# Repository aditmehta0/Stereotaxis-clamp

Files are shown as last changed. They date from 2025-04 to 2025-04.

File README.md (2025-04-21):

# 🧠 Stereotaxic Clamp Project

## 📌 Project Intent

This repository documents the design and fabrication of a **stereotaxic clamp system** used in **rodent neurosurgery**. The clamp securely positions a secondary 6 mm rod exactly **1 inch (25.4 mm)** from a primary vertical rod, enabling precise alignment of implants, microinjectors, or electrodes over a mouse skull. Two clamp designs are provided, each available for **CNC machining** and **3D printing**.

The goal is to provide an **accessible, modifiable, and affordable open-source solution** for labs conducting small animal stereotaxic procedures.

---

## 📁 Repository Structure

```
Stereotaxic_Clamp/
├── Design_Files/
│   ├── DesignB/
│   │   ├── CNC/
│   │   │   ├── DesignB_CNC_BOM.xlsx
│   │   │   └── CAD_Files/
│   │   └── 3D_Print/
│   │       ├── DesignB_3DPrinted_BOM.xlsx
│   │       └── STL_Files/
│   │       └── Instructions/
│   │           └── Assembly_Guide.md
│   └── DesignA/
│       ├── 3D_Print/
└── README.md                   # This project overview file
```

---

## 🧩 Designs Overview

- **DesignA**: Block-style clamp with parallel rod positioning and dual set screws for system where rod end insertion is not an option.
- **DesignB**: Simplified geometry clamp, optimized for rod end point insertion, less parts, simplified printing.

Each design includes:
- Fully dimensioned CAD files (`.STEP`, `.SLDPRT`)
- Ready-to-print STL files (for 3D printing)
- Manufacturing instructions for CNC or SLA
- Detailed BOMs with sourcing links

---
## 📊 Cost Comparison – DesignA

| Production Method | Total Cost (100 Units) | Cost per Part |
|---|---|---|
| 3D Printing (In-House) | $159.00 | $1.59 |

## 📊 Cost Comparison – DesignB

| Production Method | Total Cost (100 Units) | Cost per Part |
|---|---|---|
| 3D Printing (In-House) | $133.00 | $1.33 |
| CNC In-House | $494.44 | $4.94 |
| CNC External Vendor | $1,124.44 | $11.24 |

---

## 🧑‍🔬 Target Users

- Neuroscience and bioengineering labs using rodent stereotaxic frames
- Researchers needing affordable accessories for small animal surgeries
- Makers and engineers customizing implant tools for preclinical models

---

## 📬 Contributions

Feel free to fork this repo and submit pull requests with design improvements or additional variants. Design2 is ongoing — feedback welcome!

---

## 📜 License

This repository is shared under the MIT License. Attribution appreciated.

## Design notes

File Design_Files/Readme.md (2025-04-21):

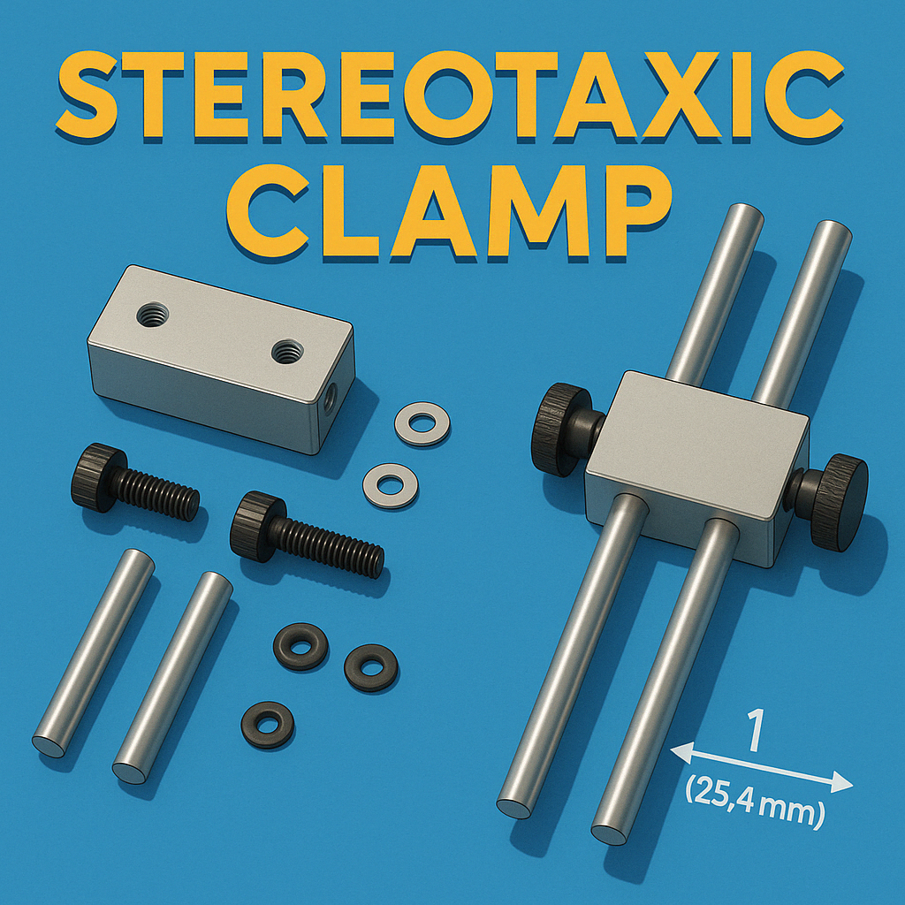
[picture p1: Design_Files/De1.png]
Stereotaxic Clamp Render

#generated by gpt

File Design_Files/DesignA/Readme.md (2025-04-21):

# 🧱 Design A – 3D Stereotaxic Clamp (Parallel Rod Mount)

This folder contains the final version of **Design A**, a stereotaxic clamp system that allows mounting a secondary 6 mm rod **1 inch (25.4 mm) center-to-center** from the primary stereotaxic frame rod.

This design is used for precise positioning of implants over rodent skulls during neurosurgical procedures.

...

Feel free to open a pull request to update your own version or request an alternate version for CNC milling (e.g., aluminum).

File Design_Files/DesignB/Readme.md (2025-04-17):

# 🧩 DesignB: Simple Clamp Design

DesignB offers a versatile stereotaxic clamp suitable for various experimental setups. It is available in both CNC-machined and 3D-printed versions.

## 🔧 Manufacturing Options

- **CNC Machining**: Precision-machined from aluminum for durability.
- **3D Printing**: Cost-effective and rapid prototyping using SLA printers.

## 📁 Subdirectories

- `CNC/`: Contains CAD files, machining instructions, and BOM for CNC manufacturing.
- `3D_Print/`: Includes STL files, printing guidelines, and BOM for 3D printing.

## 📊 Cost Comparison

| Production Method | Total Cost (100 units) | Cost per Part |
|---|---|---|
| 3D Printing (In-House) | $133.00 | $1.33 |
| CNC In-House | $494.44 | $4.94 |
| CNC External Vendor | $1,124.44 | $11.24 |

*Note: Costs are estimates and may vary based on material prices and labor rates.*

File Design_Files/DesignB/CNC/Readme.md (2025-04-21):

# 🛠️ Design1 CNC Manufacturing Guide

This directory provides all necessary files and instructions to manufacture Design1 using CNC machining.

## 📂 Contents

- `CAD_Files/`: Contains `.STEP` and `.SLDPRT` files for the clamp components.
- `BOM.xlsx`: Bill of Materials with part numbers and cost estimates.
- `DesignB_cnc.pdf`: Drawing file for Machine Shop/Machinist
## 🧾 Materials

- **Material**: 6061-T6 Aluminum
- **Stock Size**: 50mm x 25mm x 6ft bar
- **Vendors**: McMaster-Carr or Grainger

## ⚙️ Machining Notes

- Ensure proper fixturing to maintain dimensional accuracy.
- Recommended tools: 6mm end mill, M4 tap.
- Use Step file and Drawing pdf for Machine shop.

## 📌 Assembly

Refer to the visual assembly video for intuitive assembly.

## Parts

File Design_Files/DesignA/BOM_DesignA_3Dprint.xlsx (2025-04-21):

Item | Qty per Clamp | Unit Cost ($) | Total Cost ($)
DesignA_rodclamp-Middle.stl | 1 | 0.25 | 0.25
DesignA_rodclamp-Side.stl | 2 | 0.25 | 0.5
M4 × 16 mm Knurled Thumb Screws | 4 | 0.21 | 0.84

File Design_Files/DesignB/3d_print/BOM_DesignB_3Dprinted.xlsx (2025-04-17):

Item | Qty/Clamp | Unit Cost $ | Total Cost $ (100 Units) | Notes
3D Printed Clamp (SLA Resin) | 1 | 0.6 | 60 | Printed using Tough/Durable SLA resin, ~15g/part
M4 Brass Inserts (B07YSV66Y5) | 2 | 0.06 | 12 | Heat-set brass inserts, Amazon bulk
M4 Knurled Thumb Screws (NACX) | 2 | 0.2 | 40 | Amazon, B0BMG5JKY2, 100 pcs = $19.99 (buy 2×)
Nylon Washers (Optional) | 2 | 0.03 | 6 | Optional for pressure protection during tightening
Operator Assembly Time | — | 0.15 | 15 | Insert press + final fit
TOTAL |  |  | $133.00
 |  | Cost per unit: | $1.33
Print Scaling Plan | — | - | - | 3–5 SLA printers, 4–6 parts/tray. Estimated 4–6 days total.

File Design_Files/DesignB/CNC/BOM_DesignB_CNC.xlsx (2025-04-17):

Bill of Materials - External CNC vs in-house (if available)
Item | Qty/Part | Unit Cost | Total for 100 (External CNC) | Total for 100 (In-House CNC) | Notes
6061-T6 Aluminum Bar (McMaster: 9146T84, 6 ft) | - | $154.44 / 6 ft | $154.44 | $154.44 | Yield ~120 parts from 6 ft bar (50×25×15 mm blocks)
Machining | - | $6.50 | $650.00 | $100.00 | External vendor quote estimate
Tool Wear (Endmill, Tap) | - | Included | Included | $30.00 | Included in external; $30 for internal amortized
Setup & Programming | - | Included | Included | $50.00 | Included in external; $50 internal estimate
Anodizing (Optional) | - | $1.50 | $150.00 | $100.00 | Clear anodize; optional
Knurled Thumb Screws (Amazon: #B0BMG5JKY2 M4x12mm) | 2 | $0.20 | $40.00 | $40.00 | NACX 100 pcs = $19.99 (Amazon)
QC & Handling | - | $0.50 | $50.00 | $20.00 | Visual, burr check, thread test
Shipping (External only) | - | $0.30 | $30.00 | $0.00 | Only for external vendor shipping
Final |  | 163.44 | $1074.44 | $494.44
 |  | Cost per part | $11.24 | $4.94

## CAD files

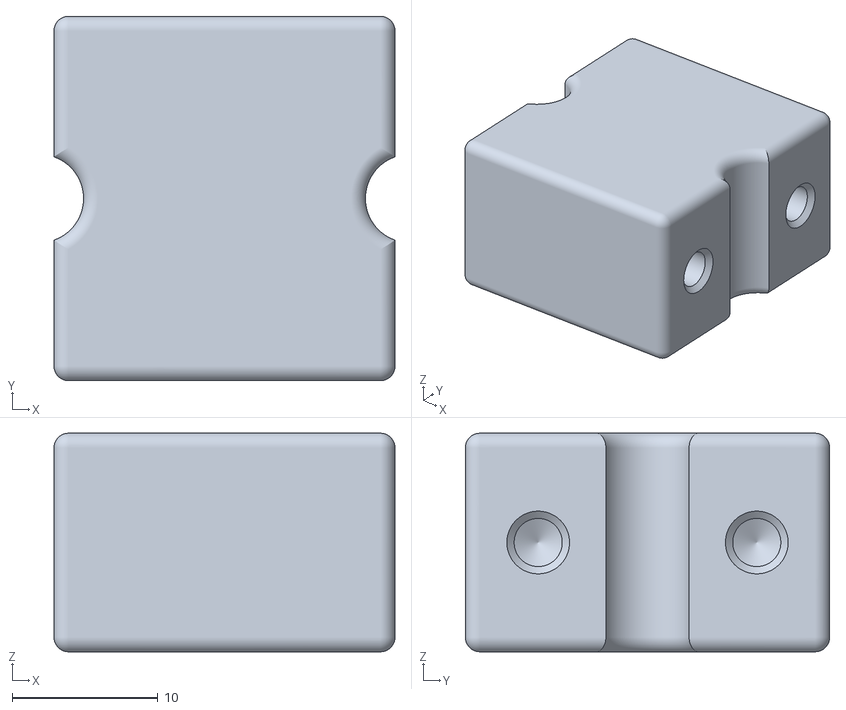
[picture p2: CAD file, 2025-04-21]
Design_Files/DesignA/3D_print/DesignA_rodclamp-Middle.STL
23.4 x 25.0 x 15.0

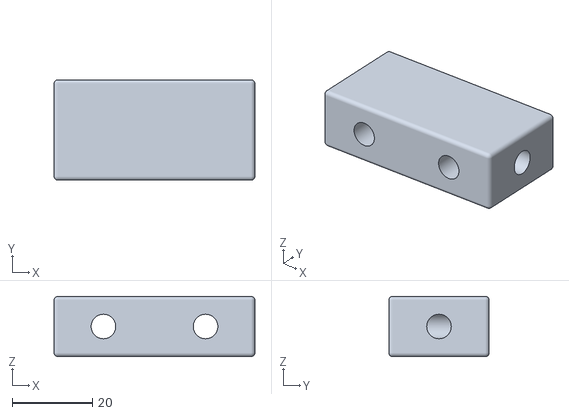
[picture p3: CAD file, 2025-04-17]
Design_Files/DesignB/3d_print/DesignB_rodClamp_withBrassInserts.STL
50.0 x 25.0 x 15.0

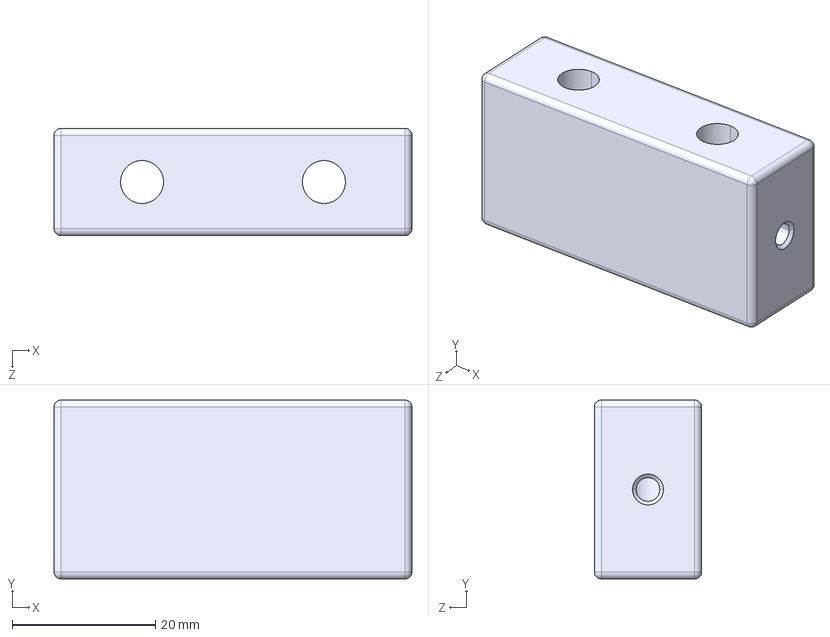
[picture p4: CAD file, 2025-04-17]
Design_Files/DesignB/CNC/DesignB_rodclamp.STEP
50.0 x 25.0 x 15.0 mm

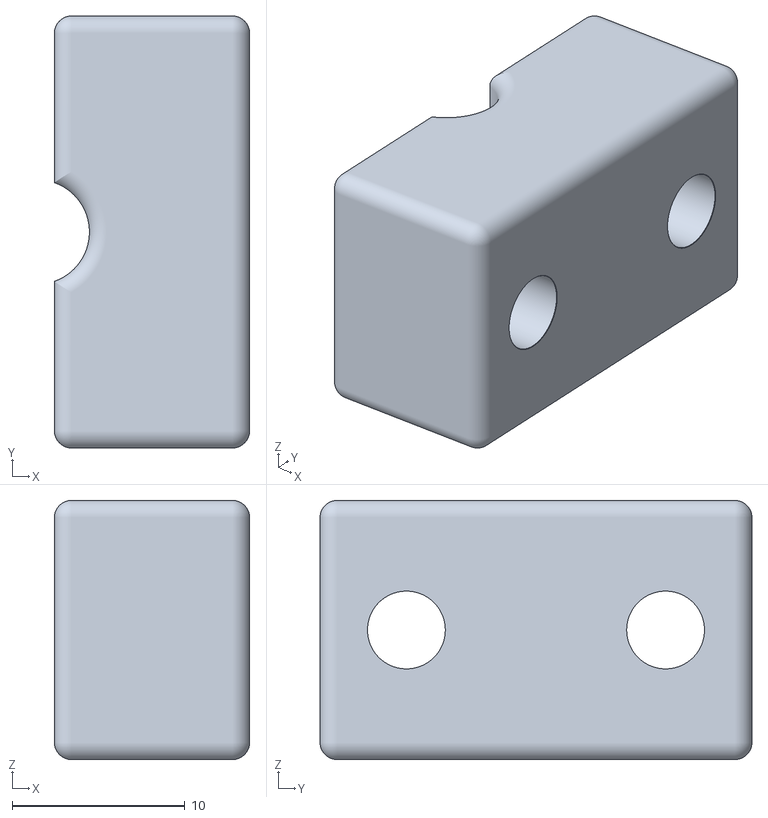
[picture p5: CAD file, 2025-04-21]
Design_Files/DesignA/3D_print/DesignA_rodclamp-Side.STL
11.3 x 25.0 x 15.0

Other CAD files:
Design_Files/DesignB/3d_print/DesignB_rodClamp_withoutBrassInserts.STL

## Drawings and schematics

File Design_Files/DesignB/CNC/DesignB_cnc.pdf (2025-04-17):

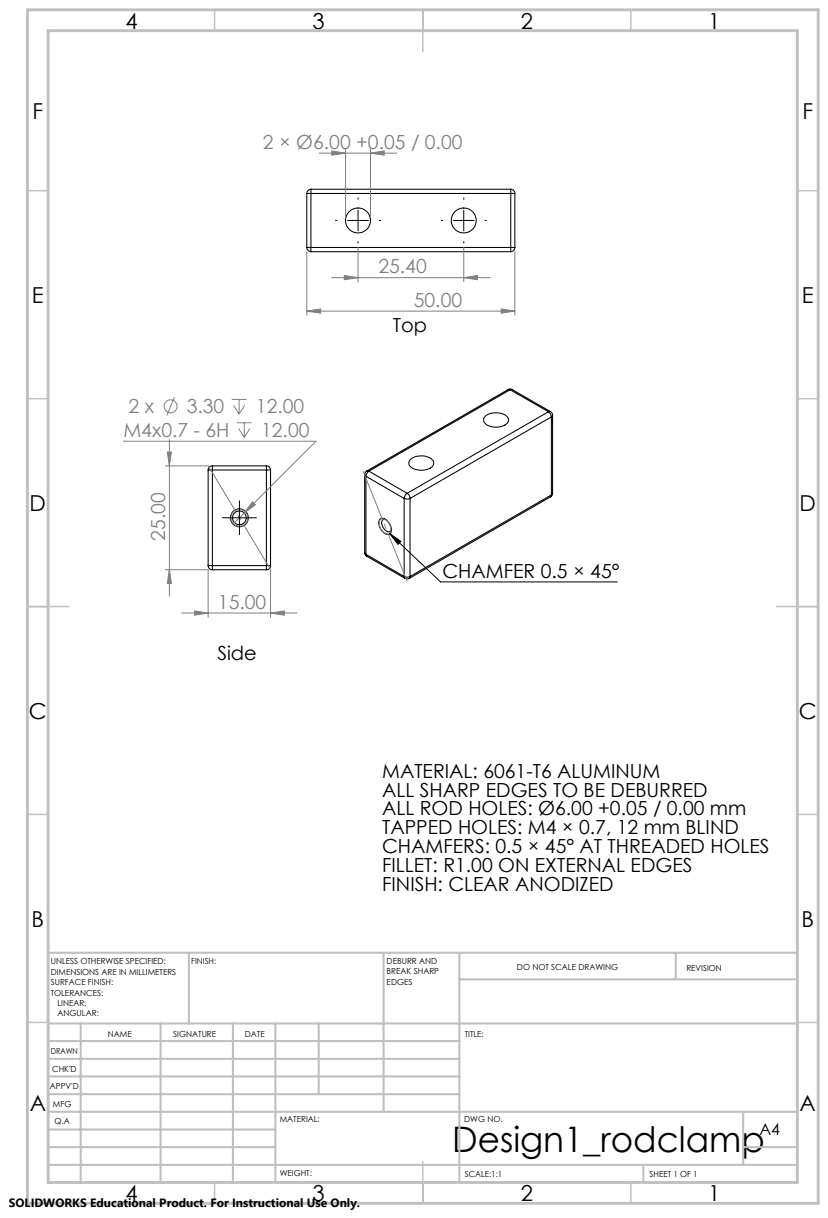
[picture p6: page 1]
CHAMFER 0.5 × 45°; FINISH:; DEBURR AND; BREAK SHARP; DO NOT SCALE DRAWING; REVISION; SCALE:1:1; SHEET 1 OF 1

MATERIAL: 6061-T6 ALUMINUM
ALL SHARP EDGES TO BE DEBURRED
ALL ROD HOLES: Ø6.00 +0.05 / 0.00 mm
TAPPED HOLES: M4 × 0.7, 12 mm BLIND
CHAMFERS: 0.5 × 45° AT THREADED HOLES
FILLET: R1.00 ON EXTERNAL EDGES
FINISH: CLEAR ANODIZED

UNLESS OTHERWISE SPECIFIED:
DIMENSIONS ARE IN MILLIMETERS
SURFACE FINISH:
TOLERANCES:
LINEAR:
ANGULAR:

NAME | SIGNATURE | DATE | | | | TITLE:

DRAWN
CHK'D
APPV'D
MFG
Q.A | | | | MATERIAL: Design1_rodclamp | DWG NO. | A4

SOLIDWORKS Educational Product. For Instructional Use Only.

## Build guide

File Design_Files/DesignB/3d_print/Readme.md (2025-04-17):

# 🖨️ Design1 3D Printing Guide

This directory contains files and instructions to produce Design1 using 3D printing methods.

## 📂 Contents

- `STL_Files/`: Ready-to-print `.STL` files for the clamp components.
- `Instructions/`: Printing guidelines and post-processing steps.
- `BOM.xlsx`: Bill of Materials with sourcing information.

## 🧵 Printing Specifications

- **Printer Type**: SLA
- **Material**: Durable resin (e.g., Formlabs Tough 2000)
- **Layer Height**: 50 microns
- **Infill**: 100% for structural integrity

## 🔩 Hardware Requirements

- **Brass Inserts**: M4 x 6mm heat-set inserts (e.g., Amazon B07YSV66Y5)
- **Thumb Screws**: M4 x 12mm knurled thumb screws (e.g., Amazon B0BMG5JKY2)
- **Optional**: Nylon washers for smoother operation

## 🧰 Assembly Instructions 

1. Print the clamp components using the provided STL files.
2. Post-process the prints as per resin manufacturer's guidelines.
3. Install brass inserts using a soldering iron with appropriate tip.
4. Assemble the clamp using the thumb screws and optional washers.

Refer to the detailed 'Assembly_clampB.mp4 for visual aids.

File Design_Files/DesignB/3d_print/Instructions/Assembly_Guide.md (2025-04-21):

# 🧰 Assembly and Usage Instructions – Design1 (3D Printed Clamp)

> ⚙️ For use with: 6 mm surgical rods spaced 25.4 mm (1 inch) apart

---

## 🔧 Tools & Materials Required

| Item | Details |
|---|---|
| **Clamp Body (Printed)** | From provided STL file — 6.1 mm rod holes |
| **M4 Brass Inserts (×2)** | Heat-set type (Amazon B07YSV66Y5, Ø outer ~5.3 mm) |
| **M4 Knurled Thumb Screws (×2)**  | NACX, M4 × 12 mm thread (Amazon B0BMG5JKY2) |
| **Optional: Nylon Washers (×2)**  | Ø4.3 mm ID, prevents damage to plastic during clamping |
| **Soldering Iron** | With flat or conical tip for brass insert setting |
| **6 mm Metal Rods** | Surgical vertical rods (100 mm long) |
| **Bench Vise or Rod Holder** | For installation into stereotaxic frame (optional) |

---

## 🖨️ 1. Print the Clamp

- **Printer Type**: SLA recommended (e.g., Formlabs, Anycubic Photon)
- **Material**: Tough or Durable Resin (Formlabs Tough 2000 recommended)
- **Orientation**: Print flat side down to minimize support on rod holes
- **Post-processing**:
  - Rinse in IPA
  - Fully cure under UV
  - Sand rod holes only if insertion is tight (>6.1 mm nominal diameter)

---

## 🔩 2. Install Brass Inserts

1. Preheat your soldering iron to ~190–210 °C
2. Align the insert vertically into the screw hole on the clamp
3. Gently press down with the iron until flush — do not over-insert
4. Let it cool undisturbed (~10 seconds)
5. Repeat for the second hole

✅ Make sure insert holes are opposite the rod holes (i.e., for horizontal screws)

For the version with no brass inserts - use a tap die hand/power tool with appropriate M4 plug tap such as: https://shorturl.at/jCm8E

---

## 🧷 3. Rod Insertion & Clamping

1. Insert the first 6 mm rod fully into either hole
   - This is the reference rod — usually the one mounted on your stereotaxic frame
2. Insert the second 6 mm rod into the opposite hole, aligning it 1 inch (25.4 mm) apart
   - This rod hovers over the mouse skull

🔧 Use knurled thumb screws to gently clamp each rod:
- Add nylon washers under screw heads (optional)
- Tighten just enough to prevent rotation/slip
- Do not overtighten to avoid thread damage

---

## 🧠 4. Deployment & Usage

- Attach the clamp to your stereotaxic rig via the reference rod
- Adjust the floating rod's position precisely above the skull
- Use the offset rod to hold:
  - Micromanipulators
  - Microinjectors
  - Implants or tool arms

✅ The design ensures fixed 1” center-to-center spacing, rotational alignment, and height control.

---

## 🧽 Maintenance Tips

- Avoid soaking clamp in solvents (e.g., acetone) — clean with IPA or mild soap
- For repeated use:
  - Use stainless steel thumbscrews
  - Check insert retention after ~20 uses

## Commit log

2025-04-17 Uploaded BOM
    [BOM_DesignB_3Dprinted.xlsx, BOM_DesignB_CNC.xlsx]
2025-04-21 Uploaded DesignA
    [BOM_DesignA_3Dprint.xlsx, DesignA_rodclamp-Middle.STL, DesignA_rodclamp-Side.STL]
